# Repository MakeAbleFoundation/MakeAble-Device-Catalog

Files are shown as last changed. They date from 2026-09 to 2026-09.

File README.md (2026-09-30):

# MakeAble assistive devices - print files for the Bambu Lab P1S

Every file here is set up for a **Bambu Lab P1S, 0.4 nozzle, textured PEI plate**, saved in Bambu Studio 2.2.2 format. Open one, check the plate, hit slice. Nothing needs to be re-arranged or re-configured.

## Printer this is for

| | |
|---|---|
| Printer | Bambu Lab **P1S** (256 x 256 x 256 mm build volume) |
| Nozzle | 0.4 mm hardened/stainless (stock) |
| Build plate | Textured PEI |
| Slicer | Bambu Studio 2.2.2 or newer (OrcaSlicer 2.4.2 also opens them) |
| Filaments | PLA (`Bambu PLA Basic @BBL X1C`) and PETG (`PETG P1S Tuned`) - one per plate |

These files are **not** for the A1, A1 mini, X1C, P2S or H2 series without re-checking: the machine settings, bed shape and the P1S's front-left bed exclusion area are baked into every plate. On another printer, re-select the machine preset in Studio and re-check part placement before slicing.

## Repository layout

- `Full Plates/` - one file per device, filled with as many copies as fit.
- `Catalogue - one device per plate.3mf` - devices 01-30, each on its own plate, one copy each, same settings.
- `Catalogue 2 - one device per plate.3mf` - devices 31-48, each on its own plate, one copy each, same settings.
- `Validation/` - what was checked, per file, plus plate previews. `Validation/tools/` holds the Python scripts that built and checked the plates.

## Full plates

| # | file | material | per plate | print time | filament | layer | walls | infill | supports | vs designer's file |
|---|---|---|---|---|---|---|---|---|---|---|
| 01 | 01 Bag Carrier (Medium) - PLA x4.3mf | PLA | 4 copies | 3h 0m 37s | 125.0 g | 0.2 mm | 2 | 15% | no | 100% |
| 02 | 02 Bag Carrier (Small) - PLA x4.3mf | PLA | 4 copies | 2h 41m 50s | 112.0 g | 0.2 mm | 2 | 15% | no | - |
| 03 | 03 Bag Carrier (Large) - PLA x2.3mf | PLA | 2 copies | 1h 49m 24s | 79.0 g | 0.2 mm | 2 | 15% | no | - |
| 04 | 04 Bottle Cap Opener - PETG x8.3mf | PETG | 8 copies | 7h 1m 48s | 166.0 g | 0.2 mm | 5 | 50% | no | 99% |
| 05 | 05 Bottle Opener (three sizes, wide handle) - PETG x4.3mf | PETG | 4 copies | 6h 46m 6s | 141.0 g | 0.2 mm | 5 | 15% | yes | 96% |
| 06 | 06 Assistive Can Tab Opener - PLA x30.3mf | PLA | 30 copies | 11h 8m 48s | 359.0 g | 0.2 mm | 2 | 50% | yes | 99% |
| 07 | 07 OPENSESAME3000 Jar Tool - PETG x2.3mf | PETG | 2 copies | 5h 57m 26s | 147.0 g | 0.12 mm | 3 | 15% | no | 100% |
| 08 | 08 KeyWings - PETG x76.3mf | PETG | 76 copies | 13h 56m 36s | 237.0 g | 0.2 mm | 3 | 20% | no | 95% |
| 09 | 09 DRAG Assistive Writer (kit of 3) - PLA x2.3mf | PLA | 2 kits | 3h 39m 32s | 146.0 g | 0.2 mm | 2 | 15% | no | 100% |
| 10 | 10 Blister Pack Opener - PETG x8.3mf | PETG | 8 copies | 8h 37m 51s | 237.0 g | 0.2 mm | 5 | 17% | yes | - |
| 11 | 11 Pill Popper - PETG x21.3mf | PETG | 21 copies | 8h 22m 50s | 166.0 g | 0.2 mm | 6 | 25% | no | 100% |
| 12 | 12 Clothes Button & Zipper Hook (hook, PETG) - PETG x9.3mf | PETG | 9 copies | 1h 43m 51s | 38.0 g | 0.2 mm | 6 | 25% | no | 96% |
| 13 | 13 Clothes Button & Zipper Hook (handle kit, PLA) - PLA x8.3mf | PLA | 8 kits | 4h 3m 50s | 99.0 g | 0.2 mm | 3/6 | 25% | no | 100% |
| 14 | 14 Flipper Nail Clipper (large clippers) - PLA x3.3mf | PLA | 3 copies | 2h 21m 17s | 91.0 g | 0.2 mm | 2 | 15% | no | 100% |
| 15 | 15 Flipper the Clipper v2 (Thingiverse) - PLA x4.3mf | PLA | 4 copies | 4h 19m 31s | 184.0 g | 0.2 mm | 2 | 80% | no | - |
| 16 | 16 Eating Utensil Aid (kit) - PLA x5.3mf | PLA | 5 kits | 9h 49m 52s | 231.0 g | 0.2 mm | 2 | 60% | no | 100% |
| 17 | 17 Quick-Slip Shoe Horn - PETG x12.3mf | PETG | 12 copies | 11h 46m 18s | 296.0 g | 0.2 mm | 2 | 15% | no | - |
| 18 | 18 Tuber Opener - PLA x12.3mf | PLA | 12 copies | 6h 51m 19s | 203.0 g | 0.16 mm | 4 | 15% | no | 100% |
| 19 | 19 Arthritis Toothbrush Grip - PLA x19.3mf | PLA | 19 copies | 13h 23m 17s | 599.0 g | 0.2 mm | 2 | 15% | no | - |
| 20 | 20 One-Handed Page Holder - PLA x23.3mf | PLA | 23 copies | 8h 10m 32s | 228.0 g | 0.16 mm | 3 | 15% | no | 100% |
| 21 | 21 Smartphone Magnification Stand - PLA x12.3mf | PLA | 12 copies | 10h 10m 51s | 312.0 g | 0.16 mm | 2 | 15% | no | 100% |
| 22 | 22 Eye Drop Assist pliers (bottle 20 mm) - PLA x2.3mf | PLA | 2 copies | 59m 33s | 29.0 g | 0.2 mm | 2 | 15% | no | - |
| 23 | 23 Eye Drop Assist pliers (bottle 22 mm) - PLA x2.3mf | PLA | 2 copies | 59m 19s | 29.0 g | 0.2 mm | 2 | 15% | no | - |
| 24 | 24 Eye Drop Assist pliers (bottle 24 mm) - PLA x2.3mf | PLA | 2 copies | 58m 59s | 29.0 g | 0.2 mm | 2 | 15% | no | - |
| 25 | 25 Eye Drop Assist pliers (bottle 25 mm) - PLA x2.3mf | PLA | 2 copies | 57m 5s | 28.0 g | 0.2 mm | 2 | 15% | no | - |
| 26 | 26 Eye Drop Assist eyepiece 03 A - PLA x35.3mf | PLA | 35 copies | 5h 5m 14s | 118.0 g | 0.2 mm | 2 | 15% | no | - |
| 27 | 27 Eye Drop Assist eyepiece 03 B - PLA x35.3mf | PLA | 35 copies | 4h 42m 50s | 113.0 g | 0.2 mm | 2 | 15% | no | - |
| 28 | 28 Eye Drop Assist eyepiece 03 C - PLA x35.3mf | PLA | 35 copies | 5h 1m 57s | 122.0 g | 0.2 mm | 2 | 15% | no | - |
| 29 | 29 Eye Drop Assist eyepiece 04 D - PLA x35.3mf | PLA | 35 copies | 5h 41m 16s | 137.0 g | 0.2 mm | 2 | 15% | no | - |
| 30 | 30 Eye Drop Assist eyepiece 04 E - PLA x35.3mf | PLA | 35 copies | 5h 21m 16s | 131.0 g | 0.2 mm | 2 | 15% | no | - |
| 31 | 31 Bedside Hook-On Storage Box (kit) - PLA x1.3mf | PLA | 1 kit | 4h 12m 24s | 229.0 g | 0.2 mm | 2 | 15% | no | 100% |
| 32 | 32 Toothpaste Squeezer, external gear (kit) - PLA x8.3mf | PLA | 8 kits | 13h 55m 52s | 323.0 g | 0.2 mm | 3 | 15%/25% | no | 100% |
| 33 | 33 Chopstick Helper (small) - PLA x48.3mf | PLA | 48 copies | 6h 18m 45s | 149.0 g | 0.2 mm | 6 | 100% | no | 99% |
| 34 | 34 Soup Can Opener (no magnets) - PETG x12.3mf | PETG | 12 copies | 6h 12m 36s | 144.0 g | 0.2 mm | 4 | 30% | no | 98% |
| 35 | 35 Jar Opener - Vacuum Releaser - PLA x8.3mf | PLA | 8 copies | 6h 20m 5s | 161.0 g | 0.24 mm | 2 | 10% | no | - |
| 36 | 36 Younger Grip Lid Wrench (no magnets) - PLA x8.3mf | PLA | 8 copies | 9h 20m 1s | 257.0 g | 0.2 mm | 3 | 10% | no | - |
| 37 | 37 Plug Puller (WATAP) - PLA x9.3mf | PLA | 9 copies | 2h 59m 51s | 84.0 g | 0.2 mm | 3 | 25% | no | 98% |
| 38 | 38 Pinky Saver 3 & Phone Stand - PLA x18.3mf | PLA | 18 copies | 5h 8m 33s | 159.0 g | 0.2 mm | 2 | 15% | no | - |
| 39 | 39 Universal Cup Holder (kit) - PLA x1.3mf | PLA | 1 kit | 5h 7m 16s | 202.0 g | 0.2 mm | 6 | 15% | yes | 98% |
| 40 | 40 Adjustable Cane Holder (kit) - PLA x6.3mf | PLA | 6 kits | 12h 45m 2s | 413.0 g | 0.2 mm | 2 | 60% | yes | - |
| 41 | 41 Hand Press - Grip Strengthener (Light) - PETG x5.3mf | PETG | 5 copies | 6h 43m 9s | 194.0 g | 0.2 mm | 4 | 15% | no | 100% |
| 42 | 42 Hand Press - Grip Strengthener (Medium) - PETG x5.3mf | PETG | 5 copies | 7h 33m 56s | 221.0 g | 0.2 mm | 5 | 15% | no | 100% |
| 43 | 43 Hand Press - Grip Strengthener (Hard) - PETG x5.3mf | PETG | 5 copies | 8h 13m 43s | 244.0 g | 0.2 mm | 6 | 15% | no | 100% |
| 44 | 44 Universal Travel Coffee Gimbal (kit) - PETG x2.3mf | PETG | 2 kits | 10h 37m 33s | 287.0 g | 0.2 mm | 4 | 15% | some parts | - |
| 45 | 45 Pen Ball (kit) - PETG x4.3mf | PETG | 4 kits | 11h 36m 55s | 261.0 g | 0.2 mm | 2 | 50% | yes | - |
| 46 | 46 Playing Card Holder (4 rows) - PLA x4.3mf | PLA | 4 copies | 7h 25m 17s | 302.0 g | 0.2 mm | 2 | 15% | no | - |
| 47 | 47 Shoe Lifter - Boot Jack - PLA x2.3mf | PLA | 2 copies | 7h 34m 35s | 282.0 g | 0.2 mm | 2 | 15% | no | 100% |
| 48 | 48 Adaptive Pencil Grip - PLA x7.3mf | PLA | 7 copies | 3h 53m 14s | 143.0 g | 0.2 mm | 2 | 15% | no | - |

All 48 plates together: about 9.0 kg of filament.

The last column is the check that matters: filament per copy on your plate against a slice of the designer's own untouched file. 100% means the part comes out exactly as they set it up. The few at 95-96% are the P1S's elephant-foot compensation shaving the first layer, which their printer profile did not apply. A dash means there is nothing to compare against (loose STLs, or a size variant that shares another file's profile, or a supplied plate, which is its own reference).

## Print-time cap

No plate runs longer than 14 hours (the slicer's estimate). Where a full plate would take longer, it holds fewer copies - the ones in the middle of the plate, kept together:

- **KeyWings**: 76 of the 88 copies that fit (13h 56m 36s)
- **Arthritis Toothbrush Grip**: 19 of the 25 copies that fit (13h 23m 17s)
- **Toothpaste Squeezer, external gear (kit)**: 8 of the 10 kits that fit (13h 55m 52s)
- **Adjustable Cane Holder (kit)**: 6 of the 10 kits that fit (12h 45m 2s)
- **Pen Ball (kit)**: 4 of the 6 kits that fit (11h 36m 55s)

## Catalogue files

A Bambu Studio project holds at most 36 plates, so the one-per-plate catalogue comes in two files.

`Catalogue - one device per plate.3mf` holds 30 plates, one device each, in the same order as the table above. Each plate keeps its own layer height, wall count, infill and support settings - those are baked onto the objects, so switching the process preset in Studio will not silently wipe them.

Filament slot 1 is PLA, slot 2 is PETG, and every plate uses one or the other, so you only ever load one spool per plate.

Three settings cannot vary per plate in Bambu Studio, so the file uses the most conservative value any device asked for:

| setting | catalogue | who wanted something else |
|---|---|---|
| first layer height | 0.2 mm | Bottle Cap Opener's profile uses 0.15 mm |
| first layer speed | 15 mm/s | the slowest any designer asked for (DRAG); others use 20-50 mm/s |
| first layer infill speed | 50 mm/s | slowest of the set |

`Catalogue 2 - one device per plate.3mf` holds 18 plates, one device each, in the same order as the table above. Each plate keeps its own layer height, wall count, infill and support settings - those are baked onto the objects, so switching the process preset in Studio will not silently wipe them.

Three settings cannot vary per plate in Bambu Studio, so the file uses the most conservative value any device asked for:

| setting | catalogue | who wanted something else |
|---|---|---|
| first layer height | 0.2 mm | Jar Opener / Vacuum Releaser's profile uses 0.24 mm |
| first layer speed | 35 mm/s | the slowest any designer asked for (Soup Can Opener); the others use 50 mm/s |
| first layer infill speed | 35 mm/s | slowest of the set |

If you want a device exactly as its designer set it up, use its file in `Full Plates/` - those keep every value.

## Spacing, and the corner the printer cannot use

Parts sit at least 5 mm apart, measured on their real outlines rather than bounding boxes, which is what lets the C-shaped ones nest into each other. Where a profile adds a brim or supports, those reach past the part itself, so the plate is sliced and the spacing widened until the slicer stops reporting conflicting toolpaths:

- **Assistive Can Tab Opener**: 8 mm apart - its tree supports flare out well past the part.
- **Universal Cup Holder (kit)**: 8 mm apart - its tree supports flare out well past the part.
- **Universal Travel Coffee Gimbal (kit)**: 8 mm apart - its tree supports flare out well past the part.

**Blister Pack Opener** is a supplied plate, arranged by hand in Bambu Studio and kept exactly as it is: its parts are 5.75 mm apart, 5.2 mm from the plate edge and 16.6 mm from the excluded corner. It slices with no conflicting toolpaths.

**Younger Grip Lid Wrench (no magnets)** is a supplied plate, arranged by hand in Bambu Studio and kept exactly as it is: its parts are 5 mm apart, 0.7 mm from the plate edge and 20.5 mm from the excluded corner. It slices with no conflicting toolpaths.

**Pinky Saver 3 & Phone Stand** is a supplied plate, arranged by hand in Bambu Studio and kept exactly as it is: its parts are 3.25 mm apart, 3 mm from the plate edge and 3 mm from the excluded corner. It slices with no conflicting toolpaths.

The P1S cannot print in an 18 x 28 mm patch at the front-left corner (Bambu calls it the bed exclusion area). Parts are kept 8 mm clear of it, and any part whose convex hull would still reach into it is dropped - the slicer refuses the whole plate over a single one.

## How the settings were decided

For each device, in order:

1. **Machine settings** always come from the P1S system preset. Nothing from the designer's printer (A1 mini, H2S, X1, X1 Carbon) is carried over - no start/end gcode, no bed shape, no kinematics.
2. **Filament** is your own preset: `PETG P1S Tuned` for PETG, `Bambu PLA Basic @BBL X1C` for PLA.
3. **Speeds, accelerations and elephant-foot compensation** follow the P1S preset, *unless* the designer had deliberately changed that value on their own printer - then their number wins.
4. **Everything else** - walls, infill, shells, supports, brim, seams, line widths, variable layer heights - is the designer's own value from their 3mf.
5. **Loose STLs** have no designer profile: they get the P1S 0.20 mm Standard profile plus only the settings the designer states on the model page.
6. Anything changed on purpose beyond that is listed per file in `Validation/per file/`.
7. **Supplied plates**, arranged by hand in Bambu Studio (Blister Pack Opener, Younger Grip Lid Wrench (no magnets), Pinky Saver 3 & Phone Stand), are delivered exactly as saved, settings included.

## How they were checked

Bambu Studio's command-line slicer crashes on macOS (a known upstream bug), so slicing checks were run with OrcaSlicer 2.4.2, which reads the same project format. Per file:

- the plate slices with no errors, and the time and filament are recorded;
- the plate finishes inside 14 hours;
- filament per copy is compared against a slice of the designer's untouched file, and against the weight quoted on the model page;
- every part is inside the plate, clear of the P1S's excluded front-left corner, with at least 5 mm between parts (checked on the real outlines, not bounding boxes); a supplied plate keeps its own spacing;
- meshes are byte-identical to the designer's, so painted seams survive;
- each object carries its settings, and every object is on a plate; a supplied plate is instead checked byte for byte against the file it came from.

Structural checks: 50 files, 0 problems. All clean.

## Also needed (not printed)

- **Plug Puller (WATAP)**: 2 small zip ties (about 15 cm / 6 in) per puller
- **Pen Ball (kit)**: 5 x #6-32 x 3/4 in round-head screws + 5 x #6-32 hex nuts per ball

## Changed on purpose

- **Jar Opener / Vacuum Releaser**: four mesh vertices forming a 0.36 mm spike under the flat base were moved up onto the base; the part stood on the spike, its first layer was empty and the slicer refused it (the designer's own file fails the same way in OrcaSlicer).

## Worth knowing (nothing was changed)

- **KeyWings**: Body_05*: tall and narrow (21 mm on a 6 mm footprint) with brim off in the designer's profile
- **DRAG Assistive Writer (kit of 3)**: DRAG left plate: 98 mm2 of steep overhang with air under it (max drop 6.1 mm at z=9 mm) while supports are off in the designer's profile - worth a look at the preview
- **DRAG Assistive Writer (kit of 3)**: DRAG right plate: 93 mm2 of steep overhang with air under it (max drop 12.9 mm at z=13 mm) while supports are off in the designer's profile - worth a look at the preview
- **Pill Popper**: Body_08*2: 247 mm2 of steep overhang with air under it (max drop 3.6 mm at z=4 mm) while supports are off in the designer's profile - worth a look at the preview
- **Clothes Button & Zipper Hook (handle kit, PLA)**: Handle+scales.stl: 1157 mm2 of steep overhang with air under it (max drop 5.0 mm at z=5 mm) while supports are off in the designer's profile - worth a look at the preview
- **Flipper Nail Clipper (large clippers)**: Flipper Clipper mod for large size nailcutter.stl: 522 mm2 of steep overhang with air under it (max drop 6.0 mm at z=8 mm) while supports are off in the designer's profile - worth a look at the preview
- **Flipper the Clipper v2 (Thingiverse)**: Flipper the Clipper v2 (Thingiverse): 452 mm2 of steep overhang with air under it (max drop 6.0 mm at z=8 mm) while supports are off in the designer's profile - worth a look at the preview
- **Eating Utensil Aid (kit)**: Spoon Holder.stl: 610 mm2 of steep overhang with air under it (max drop 21.0 mm at z=23 mm) while supports are off in the designer's profile - worth a look at the preview
- **Smartphone Magnification Stand**: Smartphone Magnification Stand.stl: 72 mm2 of steep overhang with air under it (max drop 5.0 mm at z=13 mm) while supports are off in the designer's profile - worth a look at the preview
- **Eye Drop Assist eyepiece 03 A**: Eye Drop Assist eyepiece 03 A: 130 mm2 of steep overhang with air under it (max drop 25.2 mm at z=25 mm) while supports are off in the designer's profile - worth a look at the preview
- **Eye Drop Assist eyepiece 03 C**: Eye Drop Assist eyepiece 03 C: 158 mm2 of steep overhang with air under it (max drop 25.2 mm at z=25 mm) while supports are off in the designer's profile - worth a look at the preview
- **Eye Drop Assist eyepiece 04 D**: Eye Drop Assist eyepiece 04 D: 168 mm2 of steep overhang with air under it (max drop 25.2 mm at z=25 mm) while supports are off in the designer's profile - worth a look at the preview
- **Toothpaste Squeezer, external gear (kit)**: Squeezer base (Seigaiha pattern): 186 mm2 of steep overhang with air under it (max drop 57.0 mm at z=60 mm) while supports are off in the designer's profile - worth a look at the preview
- **Toothpaste Squeezer, external gear (kit)**: Key shaft 0.7 mm (standard): 100 mm2 of steep overhang with air under it (max drop 3.9 mm at z=6 mm) while supports are off in the designer's profile - worth a look at the preview
- **Chopstick Helper (small)**: chopstick_helper_smooth.stl: 115 mm2 of steep overhang with air under it (max drop 6.1 mm at z=8 mm) while supports are off in the designer's profile - worth a look at the preview
- **Soup Can Opener (no magnets)**: Soup Can Opener v5.stl: 235 mm2 of steep overhang with air under it (max drop 3.7 mm at z=5 mm) while supports are off in the designer's profile - worth a look at the preview
- **Jar Opener / Vacuum Releaser**: Body_03: 359 mm2 of steep overhang with air under it (max drop 14.3 mm at z=20 mm) while supports are off in the designer's profile - worth a look at the preview
- **Younger Grip Lid Wrench (no magnets)**: YOUNGER__GRIP_NO Magnets_.stl: 240 mm2 of steep overhang with air under it (max drop 15.4 mm at z=15 mm) while supports are off in the designer's profile - worth a look at the preview
- **Plug Puller (WATAP)**: Plug Puller WATAP.stl: 156 mm2 of steep overhang with air under it (max drop 0.8 mm at z=1 mm) while supports are off in the designer's profile - worth a look at the preview
- **Hand Press / Grip Strengthener (Light)**: Fingergrip Press Light.stl: 67 mm2 of steep overhang with air under it (max drop 4.0 mm at z=10 mm) while supports are off in the designer's profile - worth a look at the preview
- **Hand Press / Grip Strengthener (Medium)**: Fingergrip Press Medium.stl: 67 mm2 of steep overhang with air under it (max drop 4.0 mm at z=10 mm) while supports are off in the designer's profile - worth a look at the preview
- **Hand Press / Grip Strengthener (Hard)**: Fingergrip Press Hard.stl: 67 mm2 of steep overhang with air under it (max drop 4.0 mm at z=10 mm) while supports are off in the designer's profile - worth a look at the preview
- **Universal Travel Coffee Gimbal (kit)**: Gimbal: 327 mm2 of steep overhang with air under it (max drop 2.0 mm at z=14 mm) while supports are off in the designer's profile - worth a look at the preview
- **Universal Travel Coffee Gimbal (kit)**: Bolt: 86 mm2 of steep overhang with air under it (max drop 3.7 mm at z=4 mm) while supports are off in the designer's profile - worth a look at the preview
- **Shoe Lifter / Boot Jack**: SchuhauszieherV2.stl_A_A: 11300 mm2 of steep overhang with air under it (max drop 92.0 mm at z=92 mm) while supports are off in the designer's profile - worth a look at the preview

## Where each file came from

| # | device | designer source file (kept locally, not in this repo) | model page |
|---|---|---|---|
| 01 | Bag Carrier (Medium) | `Bag Carrier (PLA)/Bag+Carrier+Medium.3mf` | [page](https://makerworld.com/en/models/1715311-bag-carrier#profileId-1820526) |
| 02 | Bag Carrier (Small) | `Bag Carrier (PLA)/Bag+Carrier+Medium.3mf` | [page](https://makerworld.com/en/models/1715311-bag-carrier) |
| 03 | Bag Carrier (Large) | `Bag Carrier (PLA)/Bag+Carrier+Medium.3mf` | [page](https://makerworld.com/en/models/1715311-bag-carrier) |
| 04 | Bottle Cap Opener | `Bottle Opener (PETG)/Bottle+Cap+Opener.3mf` | [page](https://makerworld.com/en/models/1093642-bottle-cap-opener#profileId-1087614) |
| 05 | Bottle Opener (three sizes, wide handle) | `Bottle Opener (PETG)/Bottle+Opener+remix+without+support+material.3mf` | [page](https://makerworld.com/en/models/712423-bottle-opener-three-sizes-wider-handle#profileId-642822) |
| 06 | Assistive Can Tab Opener | `Can Opener (PLA)/Base_Can_Opener.3mf` | [page](https://makerworld.com/en/models/1797256-assistive-can-tab-opener#profileId-1916191) |
| 07 | OPENSESAME3000 Jar Tool | `Jar Opener (PETG)/opensesame.3mf` | [page](https://makerworld.com/en/models/90424-opensesame3000-jar-tool#profileId-96804) |
| 08 | KeyWings | `Key Holder (PETG)/KeyWings+v6+Bambu.3mf` | [page](https://makerworld.com/en/models/1688156-keywings-for-mobility-needs#profileId-1789186) |
| 09 | DRAG Assistive Writer (kit of 3) | `DRAG Assistive Writer (PLA)/DRAG+v2 (1).3mf` | [page](https://makerworld.com/en/models/869468-drag-assistive-writing-and-drawing-device#profileId-821115) |
| 10 | Blister Pack Opener | `New Devices/BlisterPackOpener_x8.3mf` | [page](https://makerworld.com/en/models/1791626-blister-pack-opener#profileId-1909450) |
| 11 | Pill Popper | `Pill Popper (PETG)/Pill+Popper+Bambu+Studio.3mf` | [page](https://makerworld.com/en/models/1440419-pill-popper#profileId-1499190) |
| 12 | Clothes Button & Zipper Hook (hook, PETG) | `Clothes Button and Zipper Aid (PETG + PLA)/central-loop-and-hook-button-and-zipper-hook.3mf` | [page](https://makerworld.com/en/models/423231-clothes-button-and-zipper-hook-helper) |
| 13 | Clothes Button & Zipper Hook (handle kit, PLA) | `Clothes Button and Zipper Aid (PETG + PLA)/central-loop-and-hook-button-and-zipper-hook.3mf` | [page](https://makerworld.com/en/models/423231-clothes-button-and-zipper-hook-helper) |
| 14 | Flipper Nail Clipper (large clippers) | `Nail Clipper Holder (PLA)/Flipper+Clipper+mod+for+large+size+nailcutter_a1mini.3mf` | [page](https://makerworld.com/en/models/47915-flipper-the-one-handed-nail-clipper-adjusted-for-l) |
| 15 | Flipper the Clipper v2 (Thingiverse) | `Nail Clipper Holder (PLA)/Nailcutter_v2.stl` | [page](https://www.thingiverse.com/thing:5637570) |
| 16 | Eating Utensil Aid (kit) | `Eating Utensil Aid (PLA)/Eating+Utensil+Aid.3mf` | [page](https://makerworld.com/en/models/192317-eating-utensil-aid-no-supports-updated-v2-files-in#profileId-212499) |
| 17 | Quick-Slip Shoe Horn | `Shoe Horn (PETG)/Shoe+Horn+3MF.3mf` | [page](https://makerworld.com/en/models/1024414-quick-slip-shoe-horn#profileId-1006338) |
| 18 | Tuber Opener | `Tube Opener/Tube_Opener.3mf` | [page](https://makerworld.com/en/models/1737344-tuber-opener#profileId-1845987) |
| 19 | Arthritis Toothbrush Grip | `Toothbrush Grip (PLA)/6066726cbda58_arthritis-toothbrush-grip/toofbrushgrip.stl` | [page](https://www.myminifactory.com/object/3d-print-arthritis-toothbrush-grip-77601) |
| 20 | One-Handed Page Holder | `Other/One_Handed_Book_Holder.3mf` | [page](https://makerworld.com/en/models/1740474-one-handed-page-holder#profileId-1849552) |
| 21 | Smartphone Magnification Stand | `Other/Smartphone+Magnification+Stand.3mf` | [page](https://makerworld.com/en/models/1737380-smartphone-magnification-stand#profileId-1846025) |
| 22 | Eye Drop Assist pliers (bottle 20 mm) | `Eye Drop Assist (PLA)/edab_pliers_07_bd20.stl` | [page](https://www.printables.com/model/1031668-eye-drop-assist-for-bottles) |
| 23 | Eye Drop Assist pliers (bottle 22 mm) | `Eye Drop Assist (PLA)/edab_pliers_07_bd22.stl` | [page](https://www.printables.com/model/1031668-eye-drop-assist-for-bottles) |
| 24 | Eye Drop Assist pliers (bottle 24 mm) | `Eye Drop Assist (PLA)/edab_pliers_07_bd24.stl` | [page](https://www.printables.com/model/1031668-eye-drop-assist-for-bottles) |
| 25 | Eye Drop Assist pliers (bottle 25 mm) | `Eye Drop Assist (PLA)/EDA_Pliers_Bottle_06Bc_BD25.stl` | [page](https://www.printables.com/model/1031668-eye-drop-assist-for-bottles) |
| 26 | Eye Drop Assist eyepiece 03 A | `Eye Drop Assist (PLA)/EDA_EyePiece_03_A.stl` | [page](https://www.printables.com/model/1031668-eye-drop-assist-for-bottles) |
| 27 | Eye Drop Assist eyepiece 03 B | `Eye Drop Assist (PLA)/EDA_EyePiece_03_B.stl` | [page](https://www.printables.com/model/1031668-eye-drop-assist-for-bottles) |
| 28 | Eye Drop Assist eyepiece 03 C | `Eye Drop Assist (PLA)/EDA_EyePiece_03_C.stl` | [page](https://www.printables.com/model/1031668-eye-drop-assist-for-bottles) |
| 29 | Eye Drop Assist eyepiece 04 D | `Eye Drop Assist (PLA)/eda_eyepiece_04_d.stl` | [page](https://www.printables.com/model/1031668-eye-drop-assist-for-bottles) |
| 30 | Eye Drop Assist eyepiece 04 E | `Eye Drop Assist (PLA)/eda_eyepiece_04_e.stl` | [page](https://www.printables.com/model/1031668-eye-drop-assist-for-bottles) |
| 31 | Bedside Hook-On Storage Box (kit) | `New Devices/Bedside+Holder+v3.3mf` | [page](https://makerworld.com/en/models/1051323-bedside-hook-on-storage-box-organizer#profileId-1038131) |
| 32 | Toothpaste Squeezer, external gear (kit) | `New Devices/ToothSqeez_ExterGear_SeigaihaPattern.3mf` | [page](https://makerworld.com/en/models/2423006-toothpaste-squeezer-external-gear#profileId-2657457) |
| 33 | Chopstick Helper (small) | `New Devices/chopstick_helper_new_design_PLA_Small.3mf` | [page](https://makerworld.com/en/models/1088273-chopstick-helper-refreshed-design#profileId-1082781) |
| 34 | Soup Can Opener (no magnets) | `New Devices/Soup+Can+Opener+-+no+pause+for+magnets.3mf` | [page](https://makerworld.com/en/models/1030162-soup-can-opener-for-poor-grip-strength#profileId-1012846) |
| 35 | Jar Opener / Vacuum Releaser | `New Devices/Jar+Opener+Bambu+ULTRA+FAST.3mf` | [page](https://makerworld.com/en/models/1642031-jar-opener-tuned-for-all-bambu-printers#profileId-1735123) |
| 36 | Younger Grip Lid Wrench (no magnets) | `New Devices/PRJ___YOUNGER_GRIP_NO_Magnets_.3mf` | [page](https://makerworld.com/en/models/1493731-younger-grip-lid-wrench-arthritis-aid#profileId-1572614) |
| 37 | Plug Puller (WATAP) | `New Devices/Plug+Puller+by+WATAP.3mf` | [page](https://makerworld.com/en/models/421822-plug-puller-assistive-technology-by-watap#profileId-324742) |
| 38 | Pinky Saver 3 & Phone Stand | `New Devices/PinkySaver3_x19.3mf` | [page](https://makerworld.com/en/models/1842862-pinky-saver-3#profileId-1969044) |
| 39 | Universal Cup Holder (kit) | `New Devices/STOLLER_CUP_HOLDER_v2.0.3mf` | [page](https://makerworld.com/en/models/1969980-universal-cup-holder#profileId-2118034) |
| 40 | Adjustable Cane Holder (kit) | `New Devices/adjustable-cane-holder-model_files/Recommended Print Files/texture_on_cane_holder_v3.stl (+2 more)` | [page](https://www.printables.com/model/203631-adjustable-cane-holder) |
| 41 | Hand Press / Grip Strengthener (Light) | `New Devices/Fingergrip+Press (1).3mf` | [page](https://makerworld.com/en/models/531052-hand-press-grip-strengthening#profileId-447870) |
| 42 | Hand Press / Grip Strengthener (Medium) | `New Devices/Fingergrip+Press (1).3mf` | [page](https://makerworld.com/en/models/531052-hand-press-grip-strengthening#profileId-447870) |
| 43 | Hand Press / Grip Strengthener (Hard) | `New Devices/Fingergrip+Press (1).3mf` | [page](https://makerworld.com/en/models/531052-hand-press-grip-strengthening#profileId-447870) |
| 44 | Universal Travel Coffee Gimbal (kit) | `New Devices/universal-travel-coffee-gimbal-model_files/Gimbal.stl (+3 more)` | [page](https://www.printables.com/model/129329-universal-travel-coffee-gimbal) |
| 45 | Pen Ball (kit) | `New Devices/Pen Ball - 2810069/files/Pen_Ball_Top_v.1.0.0.STL (+1 more)` | [page](https://www.thingiverse.com/thing:2810069) |
| 46 | Playing Card Holder (4 rows) | `New Devices/Full Size Playing Card Holder - 2863434/files/holder-4row.stl` | [page](https://www.thingiverse.com/thing:2863434) |
| 47 | Shoe Lifter / Boot Jack | `New Devices/SchuhauszieherV2 (1).3mf` | [page](https://makerworld.com/en/models/1040127-shoe-lifter-boot-jack#profileId-1024783) |
| 48 | Adaptive Pencil Grip | `New Devices/adaptive-pencil-grip-model_files/Adaptive writer.stl` | [page](https://www.printables.com/model/520212-adaptive-pencil-grip) |

Each MakerWorld link's profile id was matched against the `DesignProfileId` stored inside the local 3mf, so these are the exact profiles that were linked. The links for 19-21 (Arthritis Toothbrush Grip, One-Handed Page Holder, Smartphone Magnification Stand) were added afterwards from the model pages themselves.

## Look-alikes that were left out

- `Other/EyeDropperAid.3mf` - MakeAble 'Eye Dropper Squeezer Aid' - a different model from the Printables Eye Drop Assist on the list
- `Other/jar-opener+(1).3mf` - MakeAble 'Jar/Pop Bottle and Can Assist' - not the OPENSESAME3000 jar tool
- `Other/4+in+1+button+aid,+key+turner,+zipper+aid,+handle.3mf` - MakeAble 4-in-1 aid - not the Clothes Button & Zipper Hook helper
- `Other/Bottle_Opener_30.stl + .gcode` - a third bottle opener, sliced for a Prusa MK3S
- `Toothbrush Grip (PLA)/toothbrush.STL` - the flat MyMiniFactory toothbrush, not the round arthritis grip you picked
- `Walking Stick Holder/` - not on the catalogue list
- `Other/DRAG+v2.3mf` - byte-identical copy of the DRAG folder's 3mf
- `Other/Tube_Opener.3mf` - plain mesh export with no settings in it
- `Aug*.3mf, Combined*.3mf, Bag_Carrier_x4.3mf` - earlier working files, not designer sources
- `Clothes Button .../*.stl (loose)` - the loose STLs differ from the 3mf: its pins are scaled to 95% and its hook carries painted seams

From the second batch (`New Devices/`):

- `adjustable-cane-holder-model_files/Design History Files/, Alternative Files/` - the designer's earlier versions and work-in-progress latch; their 'Recommended Print Files' are used
- `universal-travel-coffee-gimbal-model_files/Optional *.stl` - optional extras (long bolt, nut, cup and flat-surface adapters, vertical gimbal, TPU bar wrap); the kit is gimbal + clamp + bolt + washer
- `universal-travel-coffee-gimbal-model_files/MPC Washer.3mf, *.step, *.f3d` - a plain mesh of the washer STL that is used, and the CAD sources
- `Full Size Playing Card Holder - 2863434/files/holder.stl, case-*.stl` - the original 3-row holder and the storage cases; the 4-row holder is the one on the list
- `Full Size Playing Card Holder - 2863434/files/holder-4rows.stl` - same shape as holder-4row.stl
- `adaptive-pencil-grip-model_files/Test print.stl` - a small pencil-fit test piece
- `PRJ___YOUNGER+GRIP_Glue-in+Magnets_.3mf` - the earlier glue-in-magnets profile, replaced by the no-magnets plate
- `ToothSqeez_ExterGear_SeigaihaPattern.3mf, plates 4-6` - the 1.0, 1.3 and 1.6 mm key shafts for thicker tube ends; the kit uses the 0.7 mm standard shaft
- `Fingergrip+Press (1).3mf` - one file, three devices: each strength gets its own plate

## Still open

- **Eye Drop Assist (files 22-30)**: the three Printables pages sit behind a bot check, so the designer's own print settings could not be read. Those files use the P1S 0.20 mm Standard profile in PLA. They also need a decision: whether a pliers and an eyepiece pair up into one device (in which case they should be kit plates) or are alternatives.
- **Universal Cup Holder**: the designer's painted brim ears are carried over, but OrcaSlicer (used for these checks) does not read painted ears. Worth a glance at the first layer in Bambu Studio's preview before the first print.

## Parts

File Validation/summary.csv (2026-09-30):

id | file | device | material | per_plate | objects | print_time | grams | cm3 | cm3_per_unit | reference_cm3_per_unit | match | page_grams | layer | walls | infill | supports | brim | preset | slice_ok | geometry_issues | advisories
1 | 01 Bag Carrier (Medium) - PLA x4.3mf | Bag Carrier (Medium) | PLA | 4 copies | 4 | 3h 0m 37s | 125.4 | 99.5 | 24.88 | 24.93 | 100% | 32 | 0.2 | 2 | 15% | 0 | auto_brim | 0.20mm Standard @BBL X1C | True | 0 | 0
2 | 02 Bag Carrier (Small) - PLA x4.3mf | Bag Carrier (Small) | PLA | 4 copies | 4 | 2h 41m 50s | 112.5 | 89.2 | 22.31 |  | - |  | 0.2 | 2 | 15% | 0 | auto_brim | 0.20mm Standard @BBL X1C | True | 0 | 0
3 | 03 Bag Carrier (Large) - PLA x2.3mf | Bag Carrier (Large) | PLA | 2 copies | 2 | 1h 49m 24s | 78.9 | 62.6 | 31.32 |  | - |  | 0.2 | 2 | 15% | 0 | auto_brim | 0.20mm Standard @BBL X1C | True | 0 | 0
4 | 04 Bottle Cap Opener - PETG x8.3mf | Bottle Cap Opener | PETG | 8 copies | 8 | 7h 1m 48s | 166.0 | 132.8 | 16.6 | 16.68 | 99% | 22 | 0.2 | 5 | 50% | 0 | auto_brim | 0.20mm Standard @BBL X1C | True | 0 | 0
5 | 05 Bottle Opener (three sizes, wide handle) - PETG x4.3mf | Bottle Opener (three sizes, wide handle) | PETG | 4 copies | 4 | 6h 46m 6s | 141.1 | 112.9 | 28.22 | 29.4 | 96% | 35 | 0.2 | 5 | 15% | 1 | auto_brim | 0.20mm Strength @BBL X1C | True | 0 | 0
6 | 06 Assistive Can Tab Opener - PLA x30.3mf | Assistive Can Tab Opener | PLA | 30 copies | 30 | 11h 8m 48s | 358.8 | 284.7 | 9.49 | 9.57 | 99% | 12 | 0.2 | 2 | 50% | 1 | auto_brim | 0.20mm Standard @BBL X1C | True | 0 | 0
7 | 07 OPENSESAME3000 Jar Tool - PETG x2.3mf | OPENSESAME3000 Jar Tool | PETG | 2 copies | 2 | 5h 57m 26s | 147.1 | 117.7 | 58.83 | 58.94 | 100% | 74 | 0.12 | 3 | 15% | 0 | auto_brim | 0.12mm Fine @BBL X1C | True | 0 | 0
8 | 08 KeyWings - PETG x76.3mf | KeyWings | PETG | 76 copies | 76 | 13h 56m 36s | 237.0 | 189.6 | 2.49 | 2.63 | 95% | 4 | 0.2 | 3 | 20% | 0 | no_brim | 0.20mm Standard @BBL X1C | True | 0 | 1
9 | 09 DRAG Assistive Writer (kit of 3) - PLA x2.3mf | DRAG Assistive Writer (kit of 3) | PLA | 2 kits | 6 | 3h 39m 32s | 146.4 | 116.2 | 58.11 | 58.06 | 100% | 76 | 0.2 | 2 | 15% | 0 | no_brim | 0.20mm Standard @BBL X1C | True | 0 | 2
10 | 10 Blister Pack Opener - PETG x8.3mf | Blister Pack Opener | PETG | 8 copies | 8 | 8h 37m 51s | 237.2 | 189.7 | 23.72 |  | - | 33 | 0.2 | 5 | 17% | 1 | outer_only | 0.20mm Standard @BBL X1C | True | 0 | 0
11 | 11 Pill Popper - PETG x21.3mf | Pill Popper | PETG | 21 copies | 21 | 8h 22m 50s | 165.8 | 132.6 | 6.32 | 6.29 | 100% | 9 | 0.2 | 6 | 25% | 0 | auto_brim | 0.20mm Strength @BBL X1C | True | 0 | 1
12 | 12 Clothes Button & Zipper Hook (hook, PETG) - PETG x9.3mf | Clothes Button & Zipper Hook (hook, PETG) | PETG | 9 copies | 9 | 1h 43m 51s | 37.9 | 30.3 | 3.37 | 3.5 | 96% |  | 0.2 | 6 | 25% | 0 | auto_brim | 0.20mm Strength @BBL X1C | True | 0 | 0
13 | 13 Clothes Button & Zipper Hook (handle kit, PLA) - PLA x8.3mf | Clothes Button & Zipper Hook (handle kit, PLA) | PLA | 8 kits | 32 | 4h 3m 50s | 98.6 | 78.3 | 9.79 | 9.81 | 100% |  | 0.2 | 3/6 | 25% | 0 | auto_brim | 0.20mm Strength @BBL X1C | True | 0 | 1
14 | 14 Flipper Nail Clipper (large clippers) - PLA x3.3mf | Flipper Nail Clipper (large clippers) | PLA | 3 copies | 3 | 2h 21m 17s | 90.8 | 72.1 | 24.02 | 23.96 | 100% | 30 | 0.2 | 2 | 15% | 0 | auto_brim | 0.20mm Standard @BBL X1C | True | 0 | 1
15 | 15 Flipper the Clipper v2 (Thingiverse) - PLA x4.3mf | Flipper the Clipper v2 (Thingiverse) | PLA | 4 copies | 4 | 4h 19m 31s | 184.0 | 146.0 | 36.5 |  | - |  | 0.2 | 2 | 80% | 0 | auto_brim | 0.20mm Standard @BBL X1C | True | 0 | 1
16 | 16 Eating Utensil Aid (kit) - PLA x5.3mf | Eating Utensil Aid (kit) | PLA | 5 kits | 10 | 9h 49m 52s | 231.2 | 183.5 | 36.7 | 36.8 | 100% | 45 | 0.2 | 2 | 60% | 0 | auto_brim | 0.20mm Standard @BBL X1C | True | 0 | 1
17 | 17 Quick-Slip Shoe Horn - PETG x12.3mf | Quick-Slip Shoe Horn | PETG | 12 copies | 12 | 11h 46m 18s | 296.5 | 237.2 | 19.76 |  | - | 25 | 0.2 | 2 | 15% | 0 | auto_brim | 0.20mm Standard @BBL X1C | True | 0 | 0
18 | 18 Tuber Opener - PLA x12.3mf | Tuber Opener | PLA | 12 copies | 12 | 6h 51m 19s | 202.7 | 160.9 | 13.41 | 13.43 | 100% | 17 | 0.16 | 4 | 15% | 0 | auto_brim | 0.16mm Optimal @BBL X1C | True | 0 | 0
19 | 19 Arthritis Toothbrush Grip - PLA x19.3mf | Arthritis Toothbrush Grip | PLA | 19 copies | 19 | 13h 23m 17s | 599.3 | 475.6 | 25.03 |  | - |  | 0.2 | 2 | 15% | 0 | auto_brim | 0.20mm Standard @BBL X1C | True | 0 | 0
20 | 20 One-Handed Page Holder - PLA x23.3mf | One-Handed Page Holder | PLA | 23 copies | 23 | 8h 10m 32s | 228.1 | 181.0 | 7.87 | 7.87 | 100% |  | 0.16 | 3 | 15% | 0 | auto_brim | 0.16mm Optimal @BBL X1C | True | 0 | 0
21 | 21 Smartphone Magnification Stand - PLA x12.3mf | Smartphone Magnification Stand | PLA | 12 copies | 12 | 10h 10m 51s | 312.1 | 247.7 | 20.64 | 20.73 | 100% |  | 0.16 | 2 | 15% | 0 | auto_brim | 0.16mm Optimal @BBL X1C | True | 0 | 1
22 | 22 Eye Drop Assist pliers (bottle 20 mm) - PLA x2.3mf | Eye Drop Assist pliers (bottle 20 mm) | PLA | 2 copies | 2 | 59m 33s | 29.0 | 23.0 | 11.5 |  | - |  | 0.2 | 2 | 15% | 0 | auto_brim | 0.20mm Standard @BBL X1C | True | 0 | 0
23 | 23 Eye Drop Assist pliers (bottle 22 mm) - PLA x2.3mf | Eye Drop Assist pliers (bottle 22 mm) | PLA | 2 copies | 2 | 59m 19s | 28.7 | 22.8 | 11.4 |  | - |  | 0.2 | 2 | 15% | 0 | auto_brim | 0.20mm Standard @BBL X1C | True | 0 | 0
24 | 24 Eye Drop Assist pliers (bottle 24 mm) - PLA x2.3mf | Eye Drop Assist pliers (bottle 24 mm) | PLA | 2 copies | 2 | 58m 59s | 28.6 | 22.7 | 11.34 |  | - |  | 0.2 | 2 | 15% | 0 | auto_brim | 0.20mm Standard @BBL X1C | True | 0 | 0
25 | 25 Eye Drop Assist pliers (bottle 25 mm) - PLA x2.3mf | Eye Drop Assist pliers (bottle 25 mm) | PLA | 2 copies | 2 | 57m 5s | 27.9 | 22.2 | 11.08 |  | - |  | 0.2 | 2 | 15% | 0 | auto_brim | 0.20mm Standard @BBL X1C | True | 0 | 0
26 | 26 Eye Drop Assist eyepiece 03 A - PLA x35.3mf | Eye Drop Assist eyepiece 03 A | PLA | 35 copies | 35 | 5h 5m 14s | 117.7 | 93.4 | 2.67 |  | - |  | 0.2 | 2 | 15% | 0 | auto_brim | 0.20mm Standard @BBL X1C | True | 0 | 1
27 | 27 Eye Drop Assist eyepiece 03 B - PLA x35.3mf | Eye Drop Assist eyepiece 03 B | PLA | 35 copies | 35 | 4h 42m 50s | 113.4 | 90.0 | 2.57 |  | - |  | 0.2 | 2 | 15% | 0 | auto_brim | 0.20mm Standard @BBL X1C | True | 0 | 0
28 | 28 Eye Drop Assist eyepiece 03 C - PLA x35.3mf | Eye Drop Assist eyepiece 03 C | PLA | 35 copies | 35 | 5h 1m 57s | 122.5 | 97.2 | 2.78 |  | - |  | 0.2 | 2 | 15% | 0 | auto_brim | 0.20mm Standard @BBL X1C | True | 0 | 1
29 | 29 Eye Drop Assist eyepiece 04 D - PLA x35.3mf | Eye Drop Assist eyepiece 04 D | PLA | 35 copies | 35 | 5h 41m 16s | 136.7 | 108.5 | 3.1 |  | - |  | 0.2 | 2 | 15% | 0 | auto_brim | 0.20mm Standard @BBL X1C | True | 0 | 1
30 | 30 Eye Drop Assist eyepiece 04 E - PLA x35.3mf | Eye Drop Assist eyepiece 04 E | PLA | 35 copies | 35 | 5h 21m 16s | 130.9 | 103.9 | 2.97 |  | - |  | 0.2 | 2 | 15% | 0 | auto_brim | 0.20mm Standard @BBL X1C | True | 0 | 0
31 | 31 Bedside Hook-On Storage Box (kit) - PLA x1.3mf | Bedside Hook-On Storage Box (kit) | PLA | 1 kit | 3 | 4h 12m 24s | 229.0 | 181.7 | 181.72 | 181.24 | 100% | 223 | 0.2 | 2 | 15% | 0 | auto_brim | 0.20mm Standard @BBL X1C | True | 0 | 0
32 | 32 Toothpaste Squeezer, external gear (kit) - PLA x8.3mf | Toothpaste Squeezer, external gear (kit) | PLA | 8 kits | 24 | 13h 55m 52s | 323.4 | 256.6 | 32.08 | 32.17 | 100% | 42 | 0.2 | 3 | 15%/25% | 0 | auto_brim | 0.20mm Standard @BBL X1C | True | 0 | 2
33 | 33 Chopstick Helper (small) - PLA x48.3mf | Chopstick Helper (small) | PLA | 48 copies | 48 | 6h 18m 45s | 149.2 | 118.4 | 2.47 | 2.48 | 99% | 4 | 0.2 | 6 | 100% | 0 | auto_brim | 0.20mm Standard @BBL X1C | True | 0 | 1
34 | 34 Soup Can Opener (no magnets) - PETG x12.3mf | Soup Can Opener (no magnets) | PETG | 12 copies | 12 | 6h 12m 36s | 143.7 | 115.0 | 9.58 | 9.82 | 98% | 13 | 0.2 | 4 | 30% | 0 | auto_brim | 0.20mm Strength @BBL X1C | True | 0 | 1
35 | 35 Jar Opener - Vacuum Releaser - PLA x8.3mf | Jar Opener / Vacuum Releaser | PLA | 8 copies | 8 | 6h 20m 5s | 161.4 | 128.1 | 16.01 |  | - | 22 | 0.24 | 2 | 10% | 0 | no_brim | 0.24mm Draft @BBL X1C | True | 0 | 1
36 | 36 Younger Grip Lid Wrench (no magnets) - PLA x8.3mf | Younger Grip Lid Wrench (no magnets) | PLA | 8 copies | 8 | 9h 20m 1s | 257.3 | 204.2 | 25.52 |  | - | 33 | 0.2 | 3 | 10% | 0 | auto_brim | 0.20mm Standard @BBL X1C | True | 0 | 1
37 | 37 Plug Puller (WATAP) - PLA x9.3mf | Plug Puller (WATAP) | PLA | 9 copies | 9 | 2h 59m 51s | 84.2 | 66.8 | 7.42 | 7.59 | 98% | 10 | 0.2 | 3 | 25% | 0 | auto_brim | 0.20mm Strength @BBL X1C | True | 0 | 1
38 | 38 Pinky Saver 3 & Phone Stand - PLA x18.3mf | Pinky Saver 3 & Phone Stand | PLA | 18 copies | 18 | 5h 8m 33s | 159.0 | 126.2 | 7.01 |  | - | 9 | 0.2 | 2 | 15% | 0 | auto_brim | 0.20mm Standard @BBL X1C | True | 0 | 0
39 | 39 Universal Cup Holder (kit) - PLA x1.3mf | Universal Cup Holder (kit) | PLA | 1 kit | 10 | 5h 7m 16s | 201.8 | 160.2 | 160.19 | 162.7 | 98% | 200 | 0.2 | 6 | 15% | 1 | brim_ears | 0.20mm Standard @BBL X1C | True | 0 | 0
40 | 40 Adjustable Cane Holder (kit) - PLA x6.3mf | Adjustable Cane Holder (kit) | PLA | 6 kits | 18 | 12h 45m 2s | 413.3 | 328.0 | 54.66 |  | - |  | 0.2 | 2 | 60% | 1 | auto_brim/outer_only | 0.20mm Standard @BBL X1C | True | 0 | 0
41 | 41 Hand Press - Grip Strengthener (Light) - PETG x5.3mf | Hand Press / Grip Strengthener (Light) | PETG | 5 copies | 5 | 6h 43m 9s | 194.3 | 155.4 | 31.09 | 31.19 | 100% | 39 | 0.2 | 4 | 15% | 0 | auto_brim | 0.20mm Standard @BBL X1C | True | 0 | 1
42 | 42 Hand Press - Grip Strengthener (Medium) - PETG x5.3mf | Hand Press / Grip Strengthener (Medium) | PETG | 5 copies | 5 | 7h 33m 56s | 221.1 | 176.9 | 35.38 | 35.48 | 100% | 45 | 0.2 | 5 | 15% | 0 | auto_brim | 0.20mm Standard @BBL X1C | True | 0 | 1
43 | 43 Hand Press - Grip Strengthener (Hard) - PETG x5.3mf | Hand Press / Grip Strengthener (Hard) | PETG | 5 copies | 5 | 8h 13m 43s | 243.9 | 195.2 | 39.03 | 39.21 | 100% | 49 | 0.2 | 6 | 15% | 0 | auto_brim | 0.20mm Standard @BBL X1C | True | 0 | 1
44 | 44 Universal Travel Coffee Gimbal (kit) - PETG x2.3mf | Universal Travel Coffee Gimbal (kit) | PETG | 2 kits | 8 | 10h 37m 33s | 287.1 | 229.7 | 114.84 |  | - |  | 0.2 | 4 | 15% | some | auto_brim | 0.20mm Standard @BBL X1C | True | 0 | 2
45 | 45 Pen Ball (kit) - PETG x4.3mf | Pen Ball (kit) | PETG | 4 kits | 8 | 11h 36m 55s | 261.4 | 209.1 | 52.28 |  | - |  | 0.2 | 2 | 50% | 1 | auto_brim | 0.20mm Standard @BBL X1C | True | 0 | 0
46 | 46 Playing Card Holder (4 rows) - PLA x4.3mf | Playing Card Holder (4 rows) | PLA | 4 copies | 4 | 7h 25m 17s | 302.5 | 240.1 | 60.02 |  | - |  | 0.2 | 2 | 15% | 0 | auto_brim | 0.20mm Standard @BBL X1C | True | 0 | 0
47 | 47 Shoe Lifter - Boot Jack - PLA x2.3mf | Shoe Lifter / Boot Jack | PLA | 2 copies | 2 | 7h 34m 35s | 282.3 | 224.1 | 112.03 | 111.71 | 100% | 141 | 0.2 | 2 | 15% | 0 | auto_brim | 0.20mm Standard @BBL X1C | True | 0 | 1
48 | 48 Adaptive Pencil Grip - PLA x7.3mf | Adaptive Pencil Grip | PLA | 7 copies | 7 | 3h 53m 14s | 143.0 | 113.5 | 16.21 |  | - |  | 0.2 | 2 | 15% | 0 | auto_brim | 0.20mm Standard @BBL X1C | True | 0 | 0

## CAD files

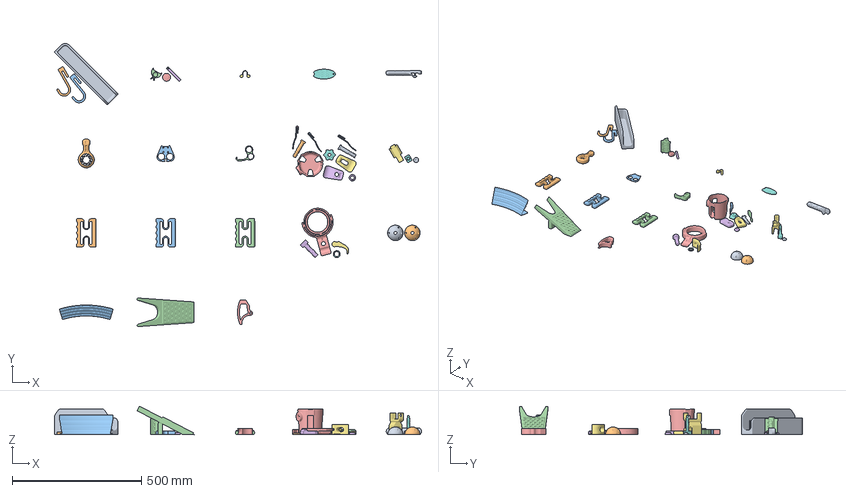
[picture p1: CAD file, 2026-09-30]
Catalogue 2 - one device per plate.3mf
1420.0 x 1094.5 x 110.2 mm
Bedside Holder v3.stl
Bedside Holder v3 hook.stl x 2
Squeezer base (Seigaiha pattern)
Key head
Key shaft 0.7 mm (standard)
chopstick_helper_smooth.stl
Soup Can Opener v5.stl
YOUNGER__GRIP_NO Magnets_.stl
Plug Puller WATAP.stl
pinky saver 3.stl
UPDATED CUP.stp
JOY-000280234
JOY-000280230
KNOB.stp
SCREW.stp_B
SCREW.stp_A
FINGERS.stp x 3
SPACER.stp
Cane holder (textured clamp)
Clamp screw (easy grip)
Clamp protector
Fingergrip Press Light.stl
Fingergrip Press Medium.stl
Fingergrip Press Hard.stl
Gimbal
Bolt
Clamp
Washer
Pen Ball top
Pen Ball bottom
Playing Card Holder (4 rows)
SchuhauszieherV2.stl_A_A
Adaptive Pencil Grip

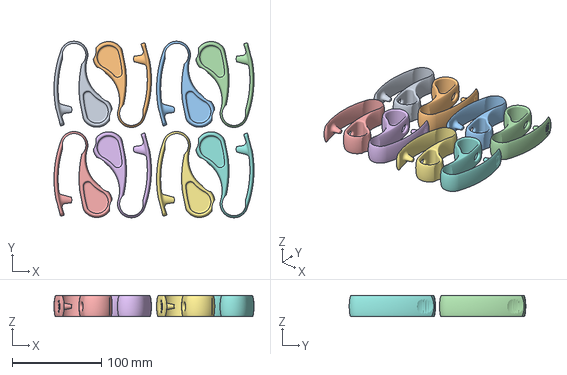
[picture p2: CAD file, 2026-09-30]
Full Plates/10 Blister Pack Opener - PETG x8.3mf
224.3 x 198.0 x 24.0 mm
Blister Pack Opener.step x 8

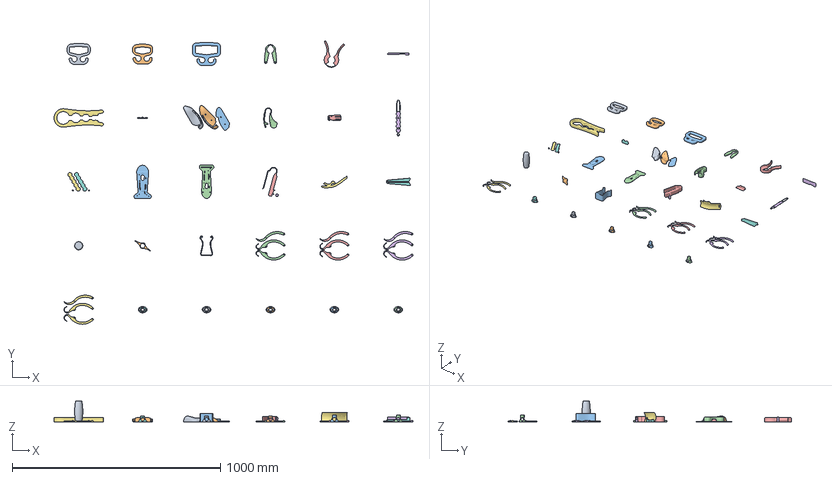
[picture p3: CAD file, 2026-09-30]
Catalogue - one device per plate.3mf
1725.3 x 1362.5 x 100.0 mm
Bag Carrier Medium.stl
Bag Carrier Small.stl
Bag Carrier Large.stl
Bottle Cap Opener
bottle opener remix.stl
Base_Can_Opener.stl
logod.stl
Body_05*
DRAG right plate
DRAG left plate
DRAG centre plate
Blister Pack Opener.step
Body_08*2
central-loop-and-hook-button-and-zipper-hook.stl
Handle+scales.stl x 2
Connector+pin.stl x 2
Flipper Clipper mod for large size nailcutter.stl
Flipper the Clipper v2 (Thingiverse)
Spoon Holder.stl
Nut for Spoon Holder.stl
Shoe Horn.stl
Tube_Opener.stl
Arthritis Toothbrush Grip
One_Handed_Book_Holder.stl
Smartphone Magnification Stand.stl
Eye Drop Assist pliers (bottle 20 mm)
Eye Drop Assist pliers (bottle 22 mm)
Eye Drop Assist pliers (bottle 24 mm)
Eye Drop Assist pliers (bottle 25 mm)
Eye Drop Assist eyepiece 03 A
Eye Drop Assist eyepiece 03 B
Eye Drop Assist eyepiece 03 C
Eye Drop Assist eyepiece 04 D
Eye Drop Assist eyepiece 04 E

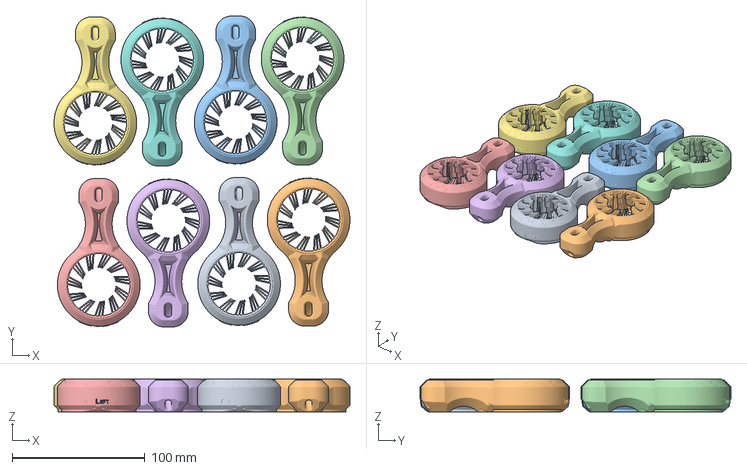
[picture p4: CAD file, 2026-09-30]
Full Plates/36 Younger Grip Lid Wrench (no magnets) - PLA x8.3mf
222.9 x 234.2 x 24.8 mm
YOUNGER__GRIP_NO Magnets_.stl x 8

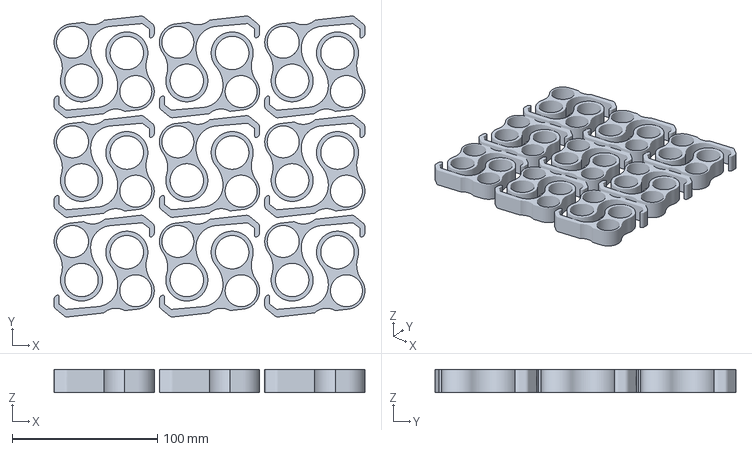
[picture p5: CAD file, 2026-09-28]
Full Plates/38 Pinky Saver 3 & Phone Stand - PLA x18.3mf
214.2 x 207.4 x 16.0 mm
pinky saver 3.stl x 18

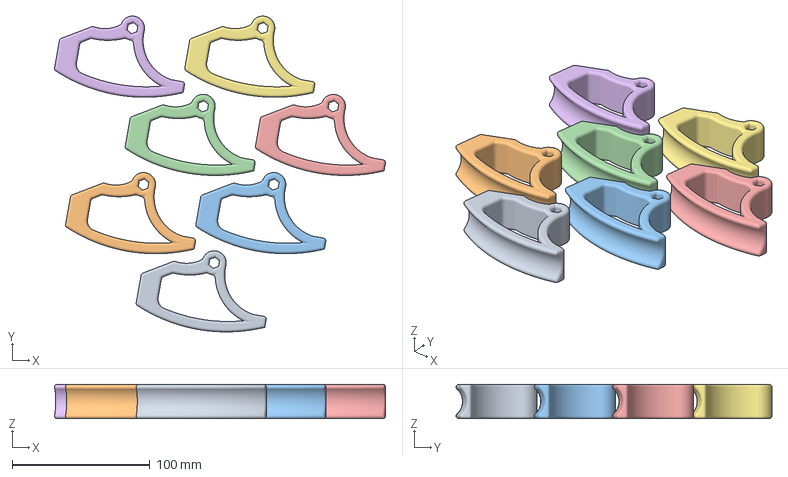
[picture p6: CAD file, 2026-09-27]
Full Plates/48 Adaptive Pencil Grip - PLA x7.3mf
240.1 x 229.1 x 25.0 mm
Adaptive Pencil Grip x 7

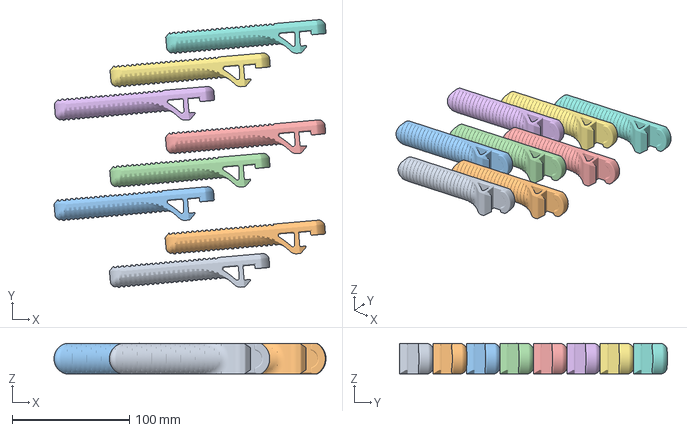
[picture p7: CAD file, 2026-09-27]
Full Plates/35 Jar Opener - Vacuum Releaser - PLA x8.3mf
232.0 x 228.5 x 26.2 mm

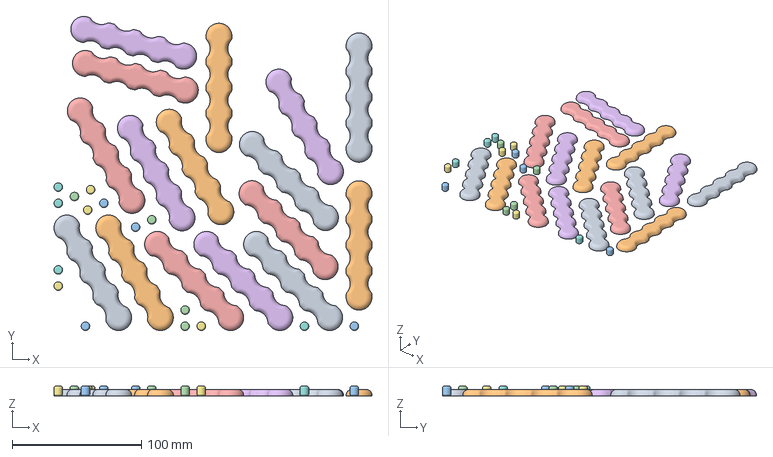
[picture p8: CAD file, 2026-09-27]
Full Plates/13 Clothes Button & Zipper Hook (handle kit, PLA) - PLA x8.3mf
245.8 x 242.7 x 7.60 mm
Handle+scales.stl x 16
Connector+pin.stl x 16

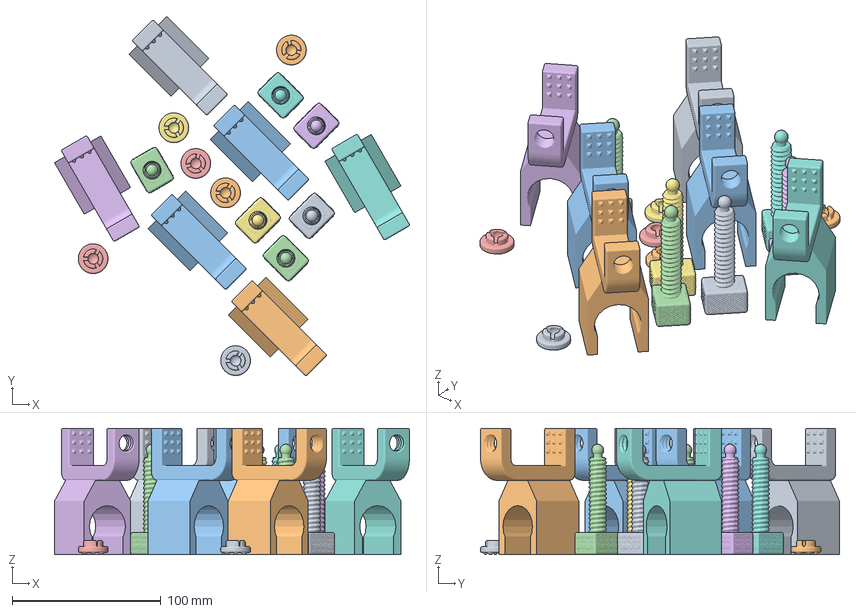
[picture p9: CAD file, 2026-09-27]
Full Plates/40 Adjustable Cane Holder (kit) - PLA x6.3mf
238.6 x 241.3 x 85.0 mm
Clamp protector x 6
Cane holder (textured clamp) x 6
Clamp screw (easy grip) x 6

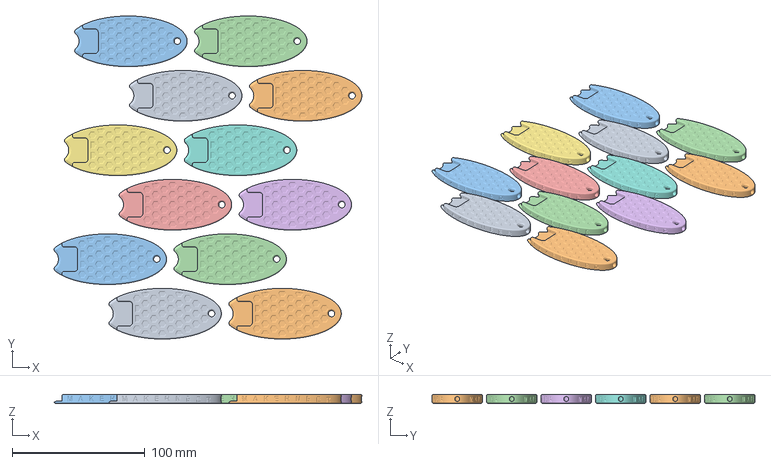
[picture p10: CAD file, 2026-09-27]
Full Plates/34 Soup Can Opener (no magnets) - PETG x12.3mf
231.7 x 243.1 x 6.75 mm
Soup Can Opener v5.stl x 12

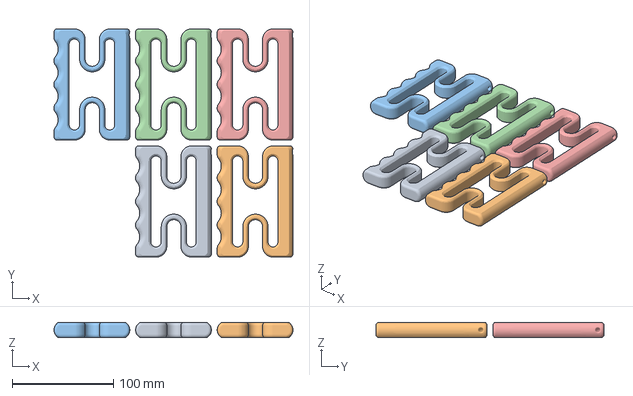
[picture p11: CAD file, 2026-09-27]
Full Plates/43 Hand Press - Grip Strengthener (Hard) - PETG x5.3mf
236.5 x 225.8 x 15.0 mm
Fingergrip Press Hard.stl x 5

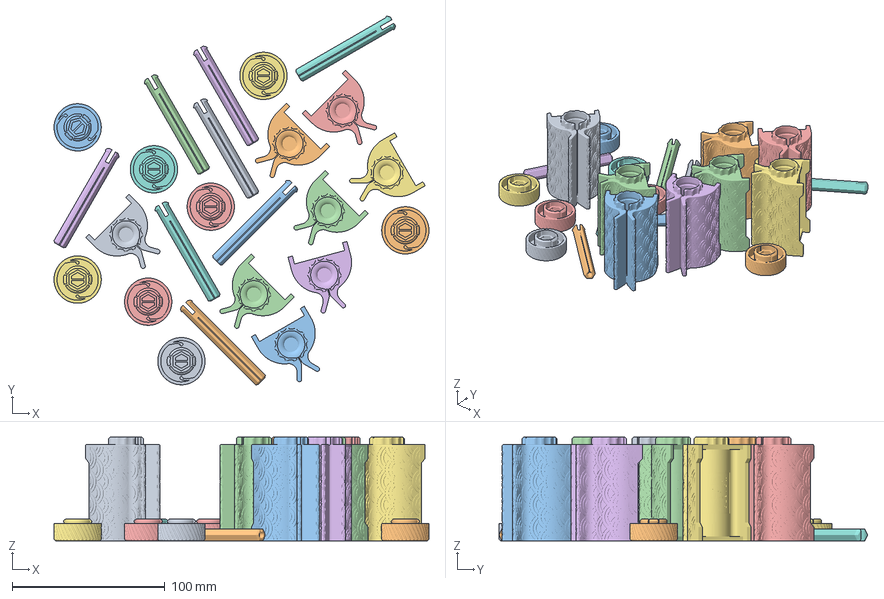
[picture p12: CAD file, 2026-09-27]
Full Plates/32 Toothpaste Squeezer, external gear (kit) - PLA x8.3mf
245.7 x 241.6 x 68.0 mm
Key head x 8
Key shaft 0.7 mm (standard) x 8
Squeezer base (Seigaiha pattern) x 8

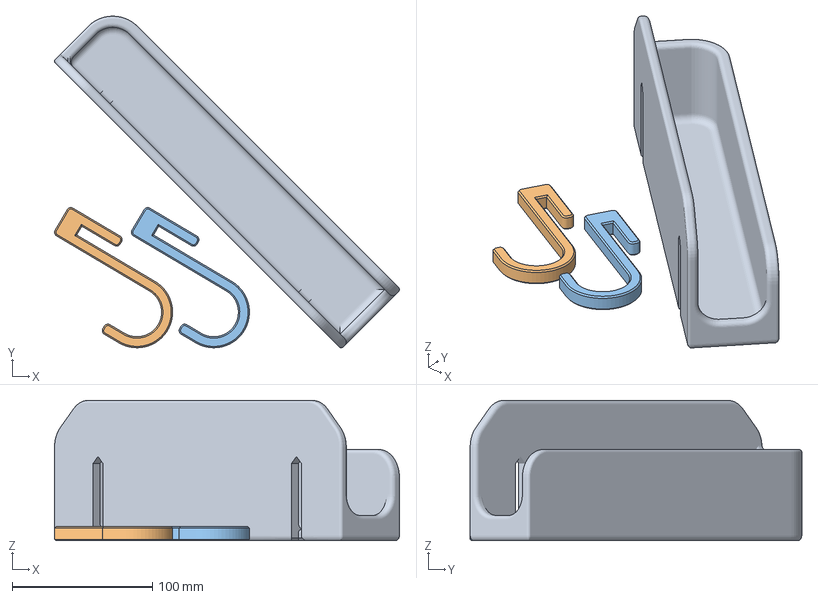
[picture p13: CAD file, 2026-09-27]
Full Plates/31 Bedside Hook-On Storage Box (kit) - PLA x1.3mf
245.8 x 236.3 x 100.0 mm
Bedside Holder v3.stl
Bedside Holder v3 hook.stl x 2

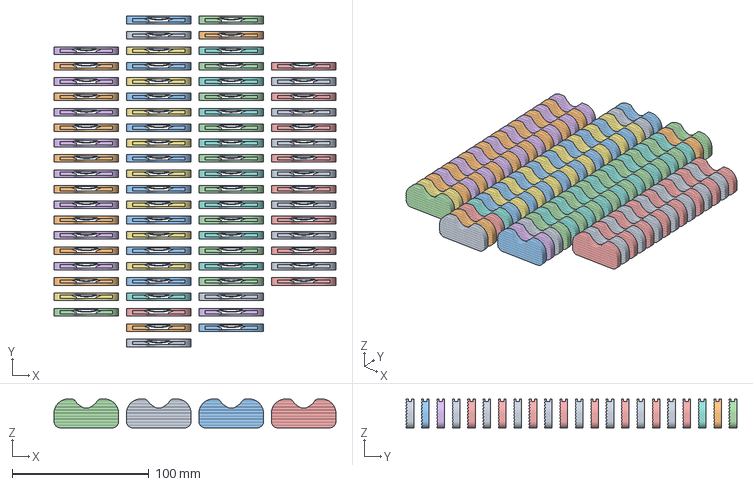
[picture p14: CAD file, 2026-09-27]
Full Plates/08 KeyWings - PETG x76.3mf
206.3 x 241.8 x 21.0 mm
Body_05* x 76

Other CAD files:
Full Plates/33 Chopstick Helper (small) - PLA x48.3mf
Full Plates/45 Pen Ball (kit) - PETG x4.3mf
Full Plates/47 Shoe Lifter - Boot Jack - PLA x2.3mf
Full Plates/44 Universal Travel Coffee Gimbal (kit) - PETG x2.3mf
Full Plates/01 Bag Carrier (Medium) - PLA x4.3mf
Full Plates/02 Bag Carrier (Small) - PLA x4.3mf
Full Plates/03 Bag Carrier (Large) - PLA x2.3mf
Full Plates/04 Bottle Cap Opener - PETG x8.3mf
Full Plates/05 Bottle Opener (three sizes, wide handle) - PETG x4.3mf
Full Plates/06 Assistive Can Tab Opener - PLA x30.3mf
Full Plates/07 OPENSESAME3000 Jar Tool - PETG x2.3mf
Full Plates/09 DRAG Assistive Writer (kit of 3) - PLA x2.3mf
Full Plates/11 Pill Popper - PETG x21.3mf
Full Plates/12 Clothes Button & Zipper Hook (hook, PETG) - PETG x9.3mf
Full Plates/14 Flipper Nail Clipper (large clippers) - PLA x3.3mf
Full Plates/15 Flipper the Clipper v2 (Thingiverse) - PLA x4.3mf
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

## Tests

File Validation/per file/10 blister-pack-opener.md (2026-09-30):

# 10 Blister Pack Opener

- file: `Full Plates/10 Blister Pack Opener - PETG x8.3mf`
- source: https://makerworld.com/en/models/1791626-blister-pack-opener#profileId-1909450
- reference 3mf: `New Devices/BlisterPackOpener_x8.3mf` (this plate, byte for byte)
- designer: MakeAble
- material: PETG (PETG P1S Tuned)
- on the plate: 8 copies (8 objects)

## Profile
| preset | layer | first layer | walls | infill | supports | brim | top/bottom |
|---|---|---|---|---|---|---|---|
| 0.20mm Standard @BBL X1C | 0.2 mm | 0.2 mm | 5 | 17% crosshatch | on tree(auto) | outer_only | 6/6 |

## How this file was made
Arranged by hand in Bambu Studio and delivered byte for byte: these tools did not pack, space, trim or re-bake it, so it keeps the project's own settings rather than per-object copies of them. The catalogue plate takes one copy from it.

## Validation
- Orca slice: passed - 8h 37m 51s, 237.2 g, 189.7 cm3
- per copie: 23.72 cm3
- the model page quotes 33 g per copy
- geometry check: clean (on the plate, clear of the excluded corner, no parts touching)
- spacing, kept as supplied: parts 5.75 mm apart (packed plates: 5 mm), 5.2 mm from the plate edge (5 mm), 16.6 mm from the excluded corner (8 mm)
- clamped for Orca only (the delivered file keeps Bambu's values): tree_support_wall_count, raft_first_layer_expansion

## Notes
- Tree supports and an outer brim are part of the designer's profile.
- Adjusted by hand in Bambu Studio from the earlier built plate (designer file `Pill Popper (PETG)/Pill+Opener.3mf`): all eight copies turned over onto their opposite face; mesh, settings and copy count unchanged.

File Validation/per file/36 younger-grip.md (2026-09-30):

# 36 Younger Grip Lid Wrench (no magnets)

- file: `Full Plates/36 Younger Grip Lid Wrench (no magnets) - PLA x8.3mf`
- source: https://makerworld.com/en/models/1493731-younger-grip-lid-wrench-arthritis-aid#profileId-1572614
- reference 3mf: `New Devices/PRJ___YOUNGER_GRIP_NO_Magnets_.3mf` (this plate, byte for byte)
- designer: SFYoung
- license: MakerWorld Standard Digital File License
- material: PLA (Bambu PLA Basic @BBL X1C)
- on the plate: 8 copies (8 objects)

## Profile
| preset | layer | first layer | walls | infill | supports | brim | top/bottom |
|---|---|---|---|---|---|---|---|
| 0.20mm Standard @BBL X1C | 0.2 mm | 0.2 mm | 3 | 10% gyroid | off | auto_brim | 5/3 |

## How this file was made
Arranged by hand in Bambu Studio and delivered byte for byte: these tools did not pack, space, trim or re-bake it, so it keeps the project's own settings rather than per-object copies of them. The catalogue plate takes one copy from it.

## Validation
- Orca slice: passed - 9h 20m 1s, 257.3 g, 204.2 cm3
- per copie: 25.52 cm3
- the model page quotes 33 g per copy
- geometry check: clean (on the plate, clear of the excluded corner, no parts touching)
- spacing, kept as supplied: parts 5 mm apart (packed plates: 5 mm), 0.7 mm from the plate edge (5 mm), 20.5 mm from the excluded corner (8 mm)
- clamped for Orca only (the delivered file keeps Bambu's values): tree_support_wall_count, raft_first_layer_expansion

## Advisories (nothing changed)
- YOUNGER__GRIP_NO Magnets_.stl: 240 mm2 of steep overhang with air under it (max drop 15.4 mm at z=15 mm) while supports are off in the designer's profile - worth a look at the preview

## Notes
- Replaces the earlier glue-in-magnets plate with the designer's 'NO MAGNETS' profile: the magnet cavities are filled in, so there is nothing to glue.
- The designer's single-colour plate, 8 copies; their profile (0.2 mm, 3 walls, 10% gyroid) on the P1S presets.
- Their height-range layer settings are kept: 0.12 mm layers over the finger-well overhang, 0.24 mm for the bridge above it, 0.2 mm elsewhere.

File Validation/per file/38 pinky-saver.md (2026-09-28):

# 38 Pinky Saver 3 & Phone Stand

- file: `Full Plates/38 Pinky Saver 3 & Phone Stand - PLA x18.3mf`
- source: https://makerworld.com/en/models/1842862-pinky-saver-3#profileId-1969044
- reference 3mf: `New Devices/PinkySaver3_x19.3mf` (this plate, byte for byte)
- designer: aqua3D
- license: MakerWorld Standard Digital File License
- material: PLA (Bambu PLA Basic @BBL X1C)
- on the plate: 18 copies (18 objects)

## Profile
| preset | layer | first layer | walls | infill | supports | brim | top/bottom |
|---|---|---|---|---|---|---|---|
| 0.20mm Standard @BBL X1C | 0.2 mm | 0.2 mm | 2 | 15% grid | off | auto_brim | 5/3 |

## How this file was made
Arranged by hand in Bambu Studio and delivered byte for byte: these tools did not pack, space, trim or re-bake it, so it keeps the project's own settings rather than per-object copies of them. The catalogue plate takes one copy from it.

## Validation
- Orca slice: passed - 5h 8m 33s, 159.0 g, 126.2 cm3
- per copie: 7.01 cm3
- the model page quotes 9 g per copy
- geometry check: clean (on the plate, clear of the excluded corner, no parts touching)
- spacing, kept as supplied: parts 3.25 mm apart (packed plates: 5 mm), 3 mm from the plate edge (5 mm), 3 mm from the excluded corner (8 mm)
- clamped for Orca only (the delivered file keeps Bambu's values): tree_support_wall_count, raft_first_layer_expansion

## Notes
- Replaces the earlier Pinky Saver & Phone Stand (standard holes, model 941286) with the designer's newer one-piece Pinky Saver 3.
- The designer's profile (0.2 mm, 2 walls, 15% infill) on the P1S presets.
- The supplied file is named x19 but holds 18 copies; Orca and Bambu's own plate thumbnail agree.

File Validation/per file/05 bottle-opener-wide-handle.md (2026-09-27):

# 05 Bottle Opener (three sizes, wide handle)

- file: `Full Plates/05 Bottle Opener (three sizes, wide handle) - PETG x4.3mf`
- source: https://makerworld.com/en/models/712423-bottle-opener-three-sizes-wider-handle#profileId-642822
- reference 3mf: `Bottle Opener (PETG)/Bottle+Opener+remix+without+support+material.3mf`
- designer: val
- material: PETG (PETG P1S Tuned)
- on the plate: 4 copies (4 objects)

## Profile
| preset | layer | first layer | walls | infill | supports | brim | top/bottom |
|---|---|---|---|---|---|---|---|
| 0.20mm Strength @BBL X1C | 0.2 mm | 0.2 mm | 5 | 15% honeycomb | on normal(auto) | auto_brim | 5/3 |

### Taken from the designer's file
| setting | P1S preset | designer |
|---|---|---|
| `independent_support_layer_height` | 1 | **0** |
| `overhang_totally_speed` | 10 | **50** |
| `sparse_infill_pattern` | grid | **cubic** |
| `support_type` | tree(auto) | **normal(auto)** |
| `tree_support_wall_count` | -1 | **0** |
| `wall_sequence` | inner wall/outer wall | **outer wall/inner wall** |

### Left at the P1S value (designer never changed it on their printer)
| setting | their file | P1S |
|---|---|---|
| `flush_multiplier` | 1 | **0.75** |
| `raft_first_layer_expansion` | 2 | **-1** |
| `top_area_threshold` | 100% | **200%** |

## Validation
- Orca slice: passed - 6h 46m 6s, 141.1 g, 112.9 cm3
- per copie: 28.22 cm3
- the designer's own file slices at 29.40 cm3 per copy (96% of that here)
- the model page quotes 35 g per copy
- geometry check: clean
- clamped for Orca only (the delivered file keeps Bambu's values): raft_first_layer_expansion

## Notes
- The designer's per-object settings (5 walls, 15% honeycomb, supports on, seam at the back) are carried over per object, as in the original.

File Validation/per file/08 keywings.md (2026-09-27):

# 08 KeyWings

- file: `Full Plates/08 KeyWings - PETG x76.3mf`
- source: https://makerworld.com/en/models/1688156-keywings-for-mobility-needs#profileId-1789186
- reference 3mf: `Key Holder (PETG)/KeyWings+v6+Bambu.3mf`
- designer: AlbertMakes
- material: PETG (PETG P1S Tuned)
- on the plate: 76 copies (76 objects)
- print-time cap: 88 copies fit on the plate; trimmed to 76 to stay under 14 h

## Profile
| preset | layer | first layer | walls | infill | supports | brim | top/bottom |
|---|---|---|---|---|---|---|---|
| 0.20mm Standard @BBL X1C | 0.2 mm | 0.2 mm | 3 | 20% grid | off | no_brim | 5/3 |

### Taken from the designer's file
| setting | P1S preset | designer |
|---|---|---|
| `bridge_speed` | 50 | **30** |
| `brim_type` | auto_brim | **no_brim** |
| `enable_arc_fitting` | 1 | **0** |
| `enable_prime_tower` | 1 | **0** |
| `inner_wall_line_width` | 0.45 | **0.5** |
| `max_travel_detour_distance` | 0 | **50** |
| `outer_wall_line_width` | 0.42 | **0.5** |
| `outer_wall_speed` | 200 | **100** |
| `overhang_2_4_speed` | 50 | **100** |
| `overhang_3_4_speed` | 30 | **100** |
| `overhang_4_4_speed` | 10 | **100** |
| `overhang_totally_speed` | 10 | **100** |
| `reduce_crossing_wall` | 0 | **1** |
| `skeleton_infill_density` | 15% | **20%** |
| `skin_infill_density` | 15% | **20%** |
| `sparse_infill_density` | 15% | **20%** |
| `tree_support_wall_count` | -1 | **0** |
| `wall_generator` | classic | **arachne** |
| `wall_loops` | 2 | **3** |
| `wall_sequence` | inner wall/outer wall | **outer wall/inner wall** |

### Left at the P1S value (designer never changed it on their printer)
| setting | their file | P1S |
|---|---|---|
| `default_acceleration` | 6000 | **10000** |
| `elefant_foot_compensation` | 0 | **0.15** |
| `flush_multiplier` | 1 | **0.75** |
| `raft_first_layer_expansion` | 2 | **-1** |
| `smooth_coefficient` | 80 | **150** |
| `travel_speed` | 700 | **500** |

## Validation
- Orca slice: passed - 13h 56m 36s, 237.0 g, 189.6 cm3
- per copie: 2.49 cm3
- the designer's own file slices at 2.63 cm3 per copy (95% of that here)
- the model page quotes 4 g per copy
- geometry check: clean
- clamped for Orca only (the delivered file keeps Bambu's values): raft_first_layer_expansion

## Advisories (nothing changed)
- Body_05*: tall and narrow (21 mm on a 6 mm footprint) with brim off in the designer's profile

## Notes
- Designer recommends PETG or nylon; brim is deliberately off in their profile.

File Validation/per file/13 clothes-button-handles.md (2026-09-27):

# 13 Clothes Button & Zipper Hook (handle kit, PLA)

- file: `Full Plates/13 Clothes Button & Zipper Hook (handle kit, PLA) - PLA x8.3mf`
- source: https://makerworld.com/en/models/423231-clothes-button-and-zipper-hook-helper
- reference 3mf: `Clothes Button and Zipper Aid (PETG + PLA)/central-loop-and-hook-button-and-zipper-hook.3mf`
- designer: Adapt3D_OT
- material: PLA (Bambu PLA Basic @BBL X1C)
- on the plate: 8 kits (32 objects)

## Profile
| preset | layer | first layer | walls | infill | supports | brim | top/bottom |
|---|---|---|---|---|---|---|---|
| 0.20mm Strength @BBL X1C | 0.2 mm | 0.2 mm | 3/6 | 25% gyroid | off | auto_brim | 5/3 |

### Taken from the designer's file
| setting | P1S preset | designer |
|---|---|---|
| `overhang_totally_speed` | 10 | **50** |
| `sparse_infill_pattern` | grid | **gyroid** |
| `support_type` | tree(auto) | **normal(auto)** |
| `tree_support_wall_count` | -1 | **0** |

### Left at the P1S value (designer never changed it on their printer)
| setting | their file | P1S |
|---|---|---|
| `flush_multiplier` | 1 | **0.75** |
| `raft_first_layer_expansion` | 2 | **-1** |
| `top_area_threshold` | 100% | **200%** |

## Validation
- Orca slice: passed - 4h 3m 50s, 98.6 g, 78.3 cm3
- per kit: 9.79 cm3
- the designer's own file slices at 9.81 cm3 per copy (100% of that here)
- geometry check: clean
- clamped for Orca only (the delivered file keeps Bambu's values): raft_first_layer_expansion

## Advisories (nothing changed)
- Handle+scales.stl: 1157 mm2 of steep overhang with air under it (max drop 5.0 mm at z=5 mm) while supports are off in the designer's profile - worth a look at the preview

## Notes
- One kit = 2 handle scales + 2 connector pins, which is what one hook needs.
- Pins are the designer's 95%-scaled version from the 3mf, not the loose STL.

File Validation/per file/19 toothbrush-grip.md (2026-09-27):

# 19 Arthritis Toothbrush Grip

- file: `Full Plates/19 Arthritis Toothbrush Grip - PLA x19.3mf`
- source: https://www.myminifactory.com/object/3d-print-arthritis-toothbrush-grip-77601
- reference 3mf: `Toothbrush Grip (PLA)/6066726cbda58_arthritis-toothbrush-grip/toofbrushgrip.stl`
- designer: MyMiniFactory
- material: PLA (Bambu PLA Basic @BBL X1C)
- on the plate: 19 copies (19 objects)
- print-time cap: 25 copies fit on the plate; trimmed to 19 to stay under 14 h

## Profile
| preset | layer | first layer | walls | infill | supports | brim | top/bottom |
|---|---|---|---|---|---|---|---|
| 0.20mm Standard @BBL X1C | 0.2 mm | 0.2 mm | 2 | 15% grid | off | auto_brim | 5/3 |

## Validation
- Orca slice: passed - 13h 23m 17s, 599.3 g, 475.6 cm3
- per copie: 25.03 cm3
- geometry check: clean
- clamped for Orca only (the delivered file keeps Bambu's values): tree_support_wall_count, raft_first_layer_expansion

## Notes
- No designer profile exists; P1S 0.20 mm Standard used.
- Heavy part: check the reported filament weight before starting a full plate.

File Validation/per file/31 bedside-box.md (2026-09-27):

# 31 Bedside Hook-On Storage Box (kit)

- file: `Full Plates/31 Bedside Hook-On Storage Box (kit) - PLA x1.3mf`
- source: https://makerworld.com/en/models/1051323-bedside-hook-on-storage-box-organizer#profileId-1038131
- reference 3mf: `New Devices/Bedside+Holder+v3.3mf`
- designer: StefB
- license: MakerWorld Standard Digital File License
- material: PLA (Bambu PLA Basic @BBL X1C)
- on the plate: 1 kit (3 objects)

## Profile
| preset | layer | first layer | walls | infill | supports | brim | top/bottom |
|---|---|---|---|---|---|---|---|
| 0.20mm Standard @BBL X1C | 0.2 mm | 0.2 mm | 2 | 15% grid | off | auto_brim | 5/3 |

### Taken from the designer's file
| setting | P1S preset | designer |
|---|---|---|
| `overhang_totally_speed` | 10 | **50** |
| `support_type` | tree(auto) | **normal(auto)** |
| `tree_support_wall_count` | -1 | **0** |

### Left at the P1S value (designer never changed it on their printer)
| setting | their file | P1S |
|---|---|---|
| `flush_multiplier` | 1 | **0.75** |
| `raft_first_layer_expansion` | 2 | **-1** |
| `top_area_threshold` | 100% | **200%** |

## Validation
- Orca slice: passed - 4h 12m 24s, 229.0 g, 181.7 cm3
- per kit: 181.72 cm3
- the designer's own file slices at 181.24 cm3 per copy (100% of that here)
- the model page quotes 223 g per copy
- geometry check: clean
- clamped for Orca only (the delivered file keeps Bambu's values): raft_first_layer_expansion

## Notes
- One kit = the storage box + two hooks, as on the designer's plate.
- The box is 240 mm long and lies diagonally across the bed. The packer cannot fit it inside the usual 5 mm margin, so the designer's own arrangement is used, centred (their X1 has the same bed and excluded corner as the P1S).
- The designer's variable layer height on the box is kept.

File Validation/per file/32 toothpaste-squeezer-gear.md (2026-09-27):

# 32 Toothpaste Squeezer, external gear (kit)

- file: `Full Plates/32 Toothpaste Squeezer, external gear (kit) - PLA x8.3mf`
- source: https://makerworld.com/en/models/2423006-toothpaste-squeezer-external-gear#profileId-2657457
- reference 3mf: `New Devices/ToothSqeez_ExterGear_SeigaihaPattern.3mf`
- designer: Tazio design
- license: MakerWorld Standard Digital File License
- material: PLA (Bambu PLA Basic @BBL X1C)
- on the plate: 8 kits (24 objects)
- print-time cap: 10 kits fit on the plate; trimmed to 8 to stay under 14 h

## Profile
| preset | layer | first layer | walls | infill | supports | brim | top/bottom |
|---|---|---|---|---|---|---|---|
| 0.20mm Standard @BBL X1C | 0.2 mm | 0.2 mm | 3 | 15%/25% grid/gyroid | off | auto_brim | 5/3 |

### Taken from the designer's file
| setting | P1S preset | designer |
|---|---|---|
| `bottom_shell_thickness` | 0 | **1** |
| `skeleton_infill_density` | 15% | **25%** |
| `skin_infill_density` | 15% | **25%** |
| `sparse_infill_density` | 15% | **25%** |
| `wall_loops` | 2 | **3** |

### Left at the P1S value (designer never changed it on their printer)
| setting | their file | P1S |
|---|---|---|
| `curr_bed_type` | Supertack Plate | **Textured PEI Plate** |
| `flush_multiplier` | 1 | **0.75** |

## Validation
- Orca slice: passed - 13h 55m 52s, 323.4 g, 256.6 cm3
- per kit: 32.08 cm3
- the designer's own file slices at 32.17 cm3 per copy (100% of that here)
- the model page quotes 42 g per copy
- geometry check: clean
- clamped for Orca only (the delivered file keeps Bambu's values): tree_support_wall_count, raft_first_layer_expansion

## Advisories (nothing changed)
- Squeezer base (Seigaiha pattern): 186 mm2 of steep overhang with air under it (max drop 57.0 mm at z=60 mm) while supports are off in the designer's profile - worth a look at the preview
- Key shaft 0.7 mm (standard): 100 mm2 of steep overhang with air under it (max drop 3.9 mm at z=6 mm) while supports are off in the designer's profile - worth a look at the preview

## Notes
- One kit = base + key head + the 0.7 mm 'Standard' key shaft. The designer also offers 1.0, 1.3 and 1.6 mm shafts for thicker tube ends (left out).
- The key parts keep the designer's own 15% gyroid; the base uses their 3 walls, 25% grid.
- Designer: PLA, PLA+, PETG or ASA - not silk PLA, which cracks at the key.

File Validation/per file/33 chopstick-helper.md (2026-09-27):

# 33 Chopstick Helper (small)

- file: `Full Plates/33 Chopstick Helper (small) - PLA x48.3mf`
- source: https://makerworld.com/en/models/1088273-chopstick-helper-refreshed-design#profileId-1082781
- reference 3mf: `New Devices/chopstick_helper_new_design_PLA_Small.3mf`
- designer: Daranto
- license: MakerWorld Standard Digital File License
- material: PLA (Bambu PLA Basic @BBL X1C)
- on the plate: 48 copies (48 objects)

## Profile
| preset | layer | first layer | walls | infill | supports | brim | top/bottom |
|---|---|---|---|---|---|---|---|
| 0.20mm Standard @BBL X1C | 0.2 mm | 0.2 mm | 6 | 100% zig-zag | off | auto_brim | 1/1 |

### Taken from the designer's file
| setting | P1S preset | designer |
|---|---|---|
| `bottom_shell_layers` | 3 | **1** |
| `bottom_surface_pattern` | monotonic | **concentric** |
| `overhang_totally_speed` | 10 | **50** |
| `seam_position` | aligned | **back** |
| `sparse_infill_density` | 15% | **100%** |
| `sparse_infill_pattern` | grid | **zig-zag** |
| `support_type` | tree(auto) | **normal(auto)** |
| `top_shell_layers` | 5 | **1** |
| `top_surface_pattern` | monotonicline | **concentric** |
| `tree_support_wall_count` | -1 | **0** |
| `wall_loops` | 2 | **6** |

### Left at the P1S value (designer never changed it on their printer)
| setting | their file | P1S |
|---|---|---|
| `flush_multiplier` | 1 | **0.75** |
| `raft_first_layer_expansion` | 2 | **-1** |
| `top_area_threshold` | 100% | **200%** |

## Validation
- Orca slice: passed - 6h 18m 45s, 149.2 g, 118.4 cm3
- per copie: 2.47 cm3
- the designer's own file slices at 2.48 cm3 per copy (99% of that here)
- the model page quotes 4 g per copy
- geometry check: clean
- clamped for Orca only (the delivered file keeps Bambu's values): raft_first_layer_expansion

## Advisories (nothing changed)
- chopstick_helper_smooth.stl: 115 mm2 of steep overhang with air under it (max drop 6.1 mm at z=8 mm) while supports are off in the designer's profile - worth a look at the preview

## Notes
- Small size: 6.12 mm holes. Medium (6.80 mm) and large (7.75 mm) exist on the page.
- Designer's profile: 6 walls, 100% infill.

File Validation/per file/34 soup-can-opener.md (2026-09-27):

# 34 Soup Can Opener (no magnets)

- file: `Full Plates/34 Soup Can Opener (no magnets) - PETG x12.3mf`
- source: https://makerworld.com/en/models/1030162-soup-can-opener-for-poor-grip-strength#profileId-1012846
- reference 3mf: `New Devices/Soup+Can+Opener+-+no+pause+for+magnets.3mf`
- designer: Makerneer
- license: CC0
- material: PETG (PETG P1S Tuned)
- on the plate: 12 copies (12 objects)

## Profile
| preset | layer | first layer | walls | infill | supports | brim | top/bottom |
|---|---|---|---|---|---|---|---|
| 0.20mm Strength @BBL X1C | 0.2 mm | 0.2 mm | 4 | 30% adaptivecubic | off | auto_brim | 5/5 |

### Taken from the designer's file
| setting | P1S preset | designer |
|---|---|---|
| `bottom_shell_layers` | 3 | **5** |
| `fuzzy_skin_point_distance` | 0.8 | **0.6** |
| `infill_wall_overlap` | 15% | **33%** |
| `initial_layer_infill_speed` | 105 | **35** |
| `initial_layer_speed` | 50 | **35** |
| `line_width` | 0.42 | **0.48** |
| `outer_wall_line_width` | 0.42 | **0.48** |
| `overhang_totally_speed` | 10 | **50** |
| `sparse_infill_density` | 25% | **30%** |
| `sparse_infill_pattern` | grid | **adaptivecubic** |
| `support_type` | tree(auto) | **normal(auto)** |
| `top_surface_line_width` | 0.42 | **0.48** |
| `tree_support_wall_count` | -1 | **0** |
| `wall_generator` | classic | **arachne** |
| `wall_loops` | 6 | **4** |

### Left at the P1S value (designer never changed it on their printer)
| setting | their file | P1S |
|---|---|---|
| `flush_multiplier` | 1 | **0.75** |
| `raft_first_layer_expansion` | 2 | **-1** |
| `top_area_threshold` | 100% | **200%** |

## Validation
- Orca slice: passed - 6h 12m 36s, 143.7 g, 115.0 cm3
- per copie: 9.58 cm3
- the designer's own file slices at 9.82 cm3 per copy (98% of that here)
- the model page quotes 13 g per copy
- geometry check: clean
- clamped for Orca only (the delivered file keeps Bambu's values): raft_first_layer_expansion

## Advisories (nothing changed)
- Soup Can Opener v5.stl: 235 mm2 of steep overhang with air under it (max drop 3.7 mm at z=5 mm) while supports are off in the designer's profile - worth a look at the preview

## Notes
- The designer printed it in Bambu PETG HF, so PETG it is.
- The 'no magnets' profile: no pause, the magnet holes stay empty.

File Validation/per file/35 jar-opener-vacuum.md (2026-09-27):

# 35 Jar Opener / Vacuum Releaser

- file: `Full Plates/35 Jar Opener - Vacuum Releaser - PLA x8.3mf`
- source: https://makerworld.com/en/models/1642031-jar-opener-tuned-for-all-bambu-printers#profileId-1735123
- reference 3mf: `New Devices/Jar+Opener+Bambu+ULTRA+FAST.3mf`
- designer: AlbertMakes
- license: MakerWorld Standard Digital File License
- material: PLA (Bambu PLA Basic @BBL X1C)
- on the plate: 8 copies (8 objects)

## Profile
| preset | layer | first layer | walls | infill | supports | brim | top/bottom |
|---|---|---|---|---|---|---|---|
| 0.24mm Draft @BBL X1C | 0.24 mm | 0.24 mm | 2 | 10% gyroid | off | no_brim | 3/3 |

### Taken from the designer's file
| setting | P1S preset | designer |
|---|---|---|
| `brim_type` | auto_brim | **no_brim** |
| `enable_circle_compensation` | 0 | **1** |
| `enable_overhang_speed` | 1 | **0** |
| `enable_prime_tower` | 1 | **0** |
| `initial_layer_print_height` | 0.2 | **0.24** |
| `precise_z_height` | 0 | **1** |
| `reduce_crossing_wall` | 0 | **1** |
| `skeleton_infill_density` | 15% | **10%** |
| `skin_infill_density` | 15% | **10%** |
| `sparse_infill_density` | 15% | **10%** |
| `sparse_infill_pattern` | grid | **gyroid** |
| `top_one_wall_type` | all top | **not apply** |
| `top_shell_layers` | 4 | **3** |
| `tree_support_wall_count` | -1 | **0** |
| `wall_sequence` | inner wall/outer wall | **outer wall/inner wall** |
| `z_direction_outwall_speed_continuous` | 0 | **1** |

### Left at the P1S value (designer never changed it on their printer)
| setting | their file | P1S |
|---|---|---|
| `curr_bed_type` | High Temp Plate | **Textured PEI Plate** |
| `default_acceleration` | 6000 | **10000** |
| `elefant_foot_compensation` | 0 | **0.15** |
| `flush_multiplier` | 1 | **0.75** |
| `raft_first_layer_expansion` | 2 | **-1** |
| `smooth_coefficient` | 80 | **150** |
| `travel_speed` | 700 | **500** |

### Deliberate changes
- mesh: four mesh vertices forming a 0.36 mm spike under the flat base were moved up onto the base; the part stood on the spike, its first layer was empty and the slicer refused it (the designer's own file fails the same way in OrcaSlicer)

## Validation
- Orca slice: passed - 6h 20m 5s, 161.4 g, 128.1 cm3
- per copie: 16.01 cm3
- the model page quotes 22 g per copy
- geometry check: clean
- clamped for Orca only (the delivered file keeps Bambu's values): raft_first_layer_expansion

## Advisories (nothing changed)
- Body_03: 359 mm2 of steep overhang with air under it (max drop 14.3 mm at z=20 mm) while supports are off in the designer's profile - worth a look at the preview

## Notes
- Mesh fix: four vertices formed a 0.1 x 0.5 mm spike 0.36 mm below the flat base, so the part stood on the spike and its first layer was empty - the slicer refuses it (the designer's own file fails the same way in OrcaSlicer). Those four vertices were moved up onto the base; nothing else in the mesh changed.
- Profile was an A1 mini 0.24 mm Draft profile; rebased onto the P1S 0.24 mm Draft.
- The page text suggests 0.2 mm, 6 walls, 60% infill; the downloaded profile uses 0.24 mm, 2 walls, 10% gyroid. The profile wins, as agreed.

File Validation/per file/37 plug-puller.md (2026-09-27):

# 37 Plug Puller (WATAP)

- file: `Full Plates/37 Plug Puller (WATAP) - PLA x9.3mf`
- source: https://makerworld.com/en/models/421822-plug-puller-assistive-technology-by-watap#profileId-324742
- reference 3mf: `New Devices/Plug+Puller+by+WATAP.3mf`
- designer: WATAP_3D
- license: CC BY-NC-SA
- material: PLA (Bambu PLA Basic @BBL X1C)
- on the plate: 9 copies (9 objects)
- also needed: 2 small zip ties (about 15 cm / 6 in) per puller

## Profile
| preset | layer | first layer | walls | infill | supports | brim | top/bottom |
|---|---|---|---|---|---|---|---|
| 0.20mm Strength @BBL X1C | 0.2 mm | 0.2 mm | 3 | 25% gyroid | off | auto_brim | 5/3 |

### Taken from the designer's file
| setting | P1S preset | designer |
|---|---|---|
| `overhang_totally_speed` | 10 | **50** |
| `sparse_infill_pattern` | grid | **gyroid** |
| `support_type` | tree(auto) | **normal(manual)** |
| `tree_support_wall_count` | -1 | **0** |
| `wall_loops` | 6 | **3** |

### Left at the P1S value (designer never changed it on their printer)
| setting | their file | P1S |
|---|---|---|
| `flush_multiplier` | 1 | **0.75** |
| `raft_first_layer_expansion` | 2 | **-1** |
| `top_area_threshold` | 100% | **200%** |

## Validation
- Orca slice: passed - 2h 59m 51s, 84.2 g, 66.8 cm3
- per copie: 7.42 cm3
- the designer's own file slices at 7.59 cm3 per copy (98% of that here)
- the model page quotes 10 g per copy
- geometry check: clean
- clamped for Orca only (the delivered file keeps Bambu's values): raft_first_layer_expansion

## Advisories (nothing changed)
- Plug Puller WATAP.stl: 156 mm2 of steep overhang with air under it (max drop 0.8 mm at z=1 mm) while supports are off in the designer's profile - worth a look at the preview

## Notes
- The designer's variable layer height is kept.

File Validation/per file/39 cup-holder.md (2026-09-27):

# 39 Universal Cup Holder (kit)

- file: `Full Plates/39 Universal Cup Holder (kit) - PLA x1.3mf`
- source: https://makerworld.com/en/models/1969980-universal-cup-holder#profileId-2118034
- reference 3mf: `New Devices/STOLLER_CUP_HOLDER_v2.0.3mf`
- designer: RED_eleven
- license: MakerWorld Standard Digital File License
- material: PLA (Bambu PLA Basic @BBL X1C)
- on the plate: 1 kit (10 objects)

## Profile
| preset | layer | first layer | walls | infill | supports | brim | top/bottom |
|---|---|---|---|---|---|---|---|
| 0.20mm Standard @BBL X1C | 0.2 mm | 0.2 mm | 6 | 15% grid | on tree(auto) | brim_ears | 5/3 |

### Taken from the designer's file
| setting | P1S preset | designer |
|---|---|---|
| `brim_type` | auto_brim | **brim_ears** |
| `enable_support` | 0 | **1** |
| `wall_loops` | 2 | **6** |

### Left at the P1S value (designer never changed it on their printer)
| setting | their file | P1S |
|---|---|---|
| `flush_multiplier` | 0.5 | **0.75** |

## Validation
- Orca slice: passed - 5h 7m 16s, 201.8 g, 160.2 cm3
- per kit: 160.19 cm3
- the designer's own file slices at 162.70 cm3 per copy (98% of that here)
- the model page quotes 200 g per copy
- geometry check: clean
- clamped for Orca only (the delivered file keeps Bambu's values): tree_support_wall_count, raft_first_layer_expansion

## Notes
- One kit = cup, both clamp halves, knob, spacer, the two halves of the split screw and three gripping fingers - the designer's 'Cup Holder & Clamp V2' plate.
- Designer's profile: 6 walls, tree supports, painted brim ears on the fingers (kept).

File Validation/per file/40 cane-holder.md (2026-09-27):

# 40 Adjustable Cane Holder (kit)

- file: `Full Plates/40 Adjustable Cane Holder (kit) - PLA x6.3mf`
- source: https://www.printables.com/model/203631-adjustable-cane-holder
- source files: `New Devices/adjustable-cane-holder-model_files/Recommended Print Files/texture_on_cane_holder_v3.stl`, `New Devices/adjustable-cane-holder-model_files/Recommended Print Files/alt_screw_updates.stl`, `New Devices/adjustable-cane-holder-model_files/Recommended Print Files/clamp_protector_tri.stl`
- designer: newhouse24 (Printables)
- license: CC BY-NC-SA 4.0
- material: PLA (Bambu PLA Basic @BBL X1C)
- on the plate: 6 kits (18 objects)
- print-time cap: 10 kits fit on the plate; trimmed to 6 to stay under 14 h

## Profile
| preset | layer | first layer | walls | infill | supports | brim | top/bottom |
|---|---|---|---|---|---|---|---|
| 0.20mm Standard @BBL X1C | 0.2 mm | 0.2 mm | 2 | 60% grid | on tree(auto) | auto_brim/outer_only | 5/3 |

### Deliberate changes
- `enable_support`: 0 -> **1**
- `skeleton_infill_density`: 15% -> **60%**
- `skin_infill_density`: 15% -> **60%**
- `sparse_infill_density`: 15% -> **60%**
- `support_base_pattern_spacing`: 2.5 -> **4**
- `support_on_build_plate_only`: 0 -> **1**

### Per-part settings
- Clamp screw (easy grip): `brim_type` = **outer_only**, `brim_width` = **5**

## Validation
- Orca slice: passed - 12h 45m 2s, 413.3 g, 328.0 cm3
- per kit: 54.66 cm3
- geometry check: clean
- clamped for Orca only (the delivered file keeps Bambu's values): tree_support_wall_count, raft_first_layer_expansion

## Notes
- The page's 'Recommended Print Files': textured holder, easy-grip screw, textured clamp protector.
- Designer's stated settings: 60% infill, supports touching the build plate at about 10% density (support line spacing 4 mm), a brim for the screw. Everything else is the P1S 0.20 mm Standard.

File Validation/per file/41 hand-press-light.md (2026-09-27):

# 41 Hand Press / Grip Strengthener (Light)

- file: `Full Plates/41 Hand Press - Grip Strengthener (Light) - PETG x5.3mf`
- source: https://makerworld.com/en/models/531052-hand-press-grip-strengthening#profileId-447870
- reference 3mf: `New Devices/Fingergrip+Press (1).3mf`
- designer: Sakul
- license: MakerWorld Standard Digital File License
- material: PETG (PETG P1S Tuned)
- on the plate: 5 copies (5 objects)

## Profile
| preset | layer | first layer | walls | infill | supports | brim | top/bottom |
|---|---|---|---|---|---|---|---|
| 0.20mm Standard @BBL X1C | 0.2 mm | 0.2 mm | 4 | 15% triangles | off | auto_brim | 6/6 |

### Taken from the designer's file
| setting | P1S preset | designer |
|---|---|---|
| `bottom_shell_layers` | 3 | **6** |
| `brim_object_gap` | 0.1 | **0** |
| `brim_width` | 5 | **7** |
| `detect_thin_wall` | 0 | **1** |
| `ironing_flow` | 10% | **20%** |
| `overhang_totally_speed` | 10 | **50** |
| `sparse_infill_pattern` | grid | **triangles** |
| `support_on_build_plate_only` | 0 | **1** |
| `support_type` | tree(auto) | **normal(auto)** |
| `top_shell_layers` | 5 | **6** |
| `tree_support_wall_count` | -1 | **0** |
| `wall_loops` | 2 | **5** |

### Left at the P1S value (designer never changed it on their printer)
| setting | their file | P1S |
|---|---|---|
| `flush_multiplier` | 1 | **0.75** |
| `raft_first_layer_expansion` | 2 | **-1** |
| `top_area_threshold` | 100% | **200%** |

## Validation
- Orca slice: passed - 6h 43m 9s, 194.3 g, 155.4 cm3
- per copie: 31.09 cm3
- the designer's own file slices at 31.19 cm3 per copy (100% of that here)
- the model page quotes 39 g per copy
- geometry check: clean
- clamped for Orca only (the delivered file keeps Bambu's values): raft_first_layer_expansion

## Advisories (nothing changed)
- Fingergrip Press Light.stl: 67 mm2 of steep overhang with air under it (max drop 4.0 mm at z=10 mm) while supports are off in the designer's profile - worth a look at the preview

## Notes
- The light grip: 4 walls (the designer's per-object setting).
- Designer: print it in PETG, PLA tends to deform.

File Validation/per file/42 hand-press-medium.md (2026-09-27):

# 42 Hand Press / Grip Strengthener (Medium)

- file: `Full Plates/42 Hand Press - Grip Strengthener (Medium) - PETG x5.3mf`
- source: https://makerworld.com/en/models/531052-hand-press-grip-strengthening#profileId-447870
- reference 3mf: `New Devices/Fingergrip+Press (1).3mf`
- designer: Sakul
- license: MakerWorld Standard Digital File License
- material: PETG (PETG P1S Tuned)
- on the plate: 5 copies (5 objects)

## Profile
| preset | layer | first layer | walls | infill | supports | brim | top/bottom |
|---|---|---|---|---|---|---|---|
| 0.20mm Standard @BBL X1C | 0.2 mm | 0.2 mm | 5 | 15% triangles | off | auto_brim | 6/6 |

### Taken from the designer's file
| setting | P1S preset | designer |
|---|---|---|
| `bottom_shell_layers` | 3 | **6** |
| `brim_object_gap` | 0.1 | **0** |
| `brim_width` | 5 | **7** |
| `detect_thin_wall` | 0 | **1** |
| `ironing_flow` | 10% | **20%** |
| `overhang_totally_speed` | 10 | **50** |
| `sparse_infill_pattern` | grid | **triangles** |
| `support_on_build_plate_only` | 0 | **1** |
| `support_type` | tree(auto) | **normal(auto)** |
| `top_shell_layers` | 5 | **6** |
| `tree_support_wall_count` | -1 | **0** |
| `wall_loops` | 2 | **5** |

### Left at the P1S value (designer never changed it on their printer)
| setting | their file | P1S |
|---|---|---|
| `flush_multiplier` | 1 | **0.75** |
| `raft_first_layer_expansion` | 2 | **-1** |
| `top_area_threshold` | 100% | **200%** |

## Validation
- Orca slice: passed - 7h 33m 56s, 221.1 g, 176.9 cm3
- per copie: 35.38 cm3
- the designer's own file slices at 35.48 cm3 per copy (100% of that here)
- the model page quotes 45 g per copy
- geometry check: clean
- clamped for Orca only (the delivered file keeps Bambu's values): raft_first_layer_expansion

## Advisories (nothing changed)
- Fingergrip Press Medium.stl: 67 mm2 of steep overhang with air under it (max drop 4.0 mm at z=10 mm) while supports are off in the designer's profile - worth a look at the preview

## Notes
- The medium grip: 5 walls (the designer's per-object setting).
- Designer: print it in PETG, PLA tends to deform.

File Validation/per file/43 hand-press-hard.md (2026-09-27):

# 43 Hand Press / Grip Strengthener (Hard)

- file: `Full Plates/43 Hand Press - Grip Strengthener (Hard) - PETG x5.3mf`
- source: https://makerworld.com/en/models/531052-hand-press-grip-strengthening#profileId-447870
- reference 3mf: `New Devices/Fingergrip+Press (1).3mf`
- designer: Sakul
- license: MakerWorld Standard Digital File License
- material: PETG (PETG P1S Tuned)
- on the plate: 5 copies (5 objects)

## Profile
| preset | layer | first layer | walls | infill | supports | brim | top/bottom |
|---|---|---|---|---|---|---|---|
| 0.20mm Standard @BBL X1C | 0.2 mm | 0.2 mm | 6 | 15% triangles | off | auto_brim | 6/6 |

### Taken from the designer's file
| setting | P1S preset | designer |
|---|---|---|
| `bottom_shell_layers` | 3 | **6** |
| `brim_object_gap` | 0.1 | **0** |
| `brim_width` | 5 | **7** |
| `detect_thin_wall` | 0 | **1** |
| `ironing_flow` | 10% | **20%** |
| `overhang_totally_speed` | 10 | **50** |
| `sparse_infill_pattern` | grid | **triangles** |
| `support_on_build_plate_only` | 0 | **1** |
| `support_type` | tree(auto) | **normal(auto)** |
| `top_shell_layers` | 5 | **6** |
| `tree_support_wall_count` | -1 | **0** |
| `wall_loops` | 2 | **5** |

### Left at the P1S value (designer never changed it on their printer)
| setting | their file | P1S |
|---|---|---|
| `flush_multiplier` | 1 | **0.75** |
| `raft_first_layer_expansion` | 2 | **-1** |
| `top_area_threshold` | 100% | **200%** |

## Validation
- Orca slice: passed - 8h 13m 43s, 243.9 g, 195.2 cm3
- per copie: 39.03 cm3
- the designer's own file slices at 39.21 cm3 per copy (100% of that here)
- the model page quotes 49 g per copy
- geometry check: clean
- clamped for Orca only (the delivered file keeps Bambu's values): raft_first_layer_expansion

## Advisories (nothing changed)
- Fingergrip Press Hard.stl: 67 mm2 of steep overhang with air under it (max drop 4.0 mm at z=10 mm) while supports are off in the designer's profile - worth a look at the preview

## Notes
- The hard grip: 6 walls (the designer's per-object setting).
- Designer: print it in PETG, PLA tends to deform.

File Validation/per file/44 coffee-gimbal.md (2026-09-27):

# 44 Universal Travel Coffee Gimbal (kit)

- file: `Full Plates/44 Universal Travel Coffee Gimbal (kit) - PETG x2.3mf`
- source: https://www.printables.com/model/129329-universal-travel-coffee-gimbal
- source files: `New Devices/universal-travel-coffee-gimbal-model_files/Gimbal.stl`, `New Devices/universal-travel-coffee-gimbal-model_files/Clamp.stl`, `New Devices/universal-travel-coffee-gimbal-model_files/Bolt.stl`, `New Devices/universal-travel-coffee-gimbal-model_files/MPC Washer.stl`
- designer: mobiobi (Printables)
- license: CC BY-NC 4.0
- material: PETG (PETG P1S Tuned)
- on the plate: 2 kits (8 objects)

## Profile
| preset | layer | first layer | walls | infill | supports | brim | top/bottom |
|---|---|---|---|---|---|---|---|
| 0.20mm Standard @BBL X1C | 0.2 mm | 0.2 mm | 4 | 15% grid | some parts, tree(auto) | auto_brim | 5/3 |

### Deliberate changes
- `wall_loops`: 2 -> **4**

### Per-part settings
- Clamp: `enable_support` = **1**, `support_type` = **tree(auto)**, `support_on_build_plate_only` = **1**

## Validation
- Orca slice: passed - 10h 37m 33s, 287.1 g, 229.7 cm3
- per kit: 114.84 cm3
- geometry check: clean
- clamped for Orca only (the delivered file keeps Bambu's values): tree_support_wall_count, raft_first_layer_expansion

## Advisories (nothing changed)
- Gimbal: 327 mm2 of steep overhang with air under it (max drop 2.0 mm at z=14 mm) while supports are off in the designer's profile - worth a look at the preview
- Bolt: 86 mm2 of steep overhang with air under it (max drop 3.7 mm at z=4 mm) while supports are off in the designer's profile - worth a look at the preview

## Notes
- One kit = gimbal + clamp + bolt + washer. The optional long bolt, nut, cup and flat-surface adapters, vertical gimbal and TPU bar wrap are left out.
- Designer: 4 perimeters, no supports on the gimbal. The clamp has a large overhang in its print orientation, so it alone gets tree supports.
- PETG rather than PLA: it holds hot cups and may sit on a car dashboard.

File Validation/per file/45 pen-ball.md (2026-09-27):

# 45 Pen Ball (kit)

- file: `Full Plates/45 Pen Ball (kit) - PETG x4.3mf`
- source: https://www.thingiverse.com/thing:2810069
- source files: `New Devices/Pen Ball - 2810069/files/Pen_Ball_Top_v.1.0.0.STL`, `New Devices/Pen Ball - 2810069/files/Pen_Ball_Bottom_v.1.0.0.stl`
- designer: makersmakingchange (Thingiverse)
- license: CC BY-NC-SA
- material: PETG (PETG P1S Tuned)
- on the plate: 4 kits (8 objects)
- print-time cap: 6 kits fit on the plate; trimmed to 4 to stay under 14 h
- also needed: 5 x #6-32 x 3/4 in round-head screws + 5 x #6-32 hex nuts per ball

## Profile
| preset | layer | first layer | walls | infill | supports | brim | top/bottom |
|---|---|---|---|---|---|---|---|
| 0.20mm Standard @BBL X1C | 0.2 mm | 0.2 mm | 2 | 50% grid | on tree(auto) | auto_brim | 5/3 |

### Deliberate changes
- `enable_support`: 0 -> **1**
- `skeleton_infill_density`: 15% -> **50%**
- `skin_infill_density`: 15% -> **50%**
- `sparse_infill_density`: 15% -> **50%**
- `support_on_build_plate_only`: 0 -> **1**

## Validation
- Orca slice: passed - 11h 36m 55s, 261.4 g, 209.1 cm3
- per kit: 52.28 cm3
- geometry check: clean
- clamped for Orca only (the delivered file keeps Bambu's values): tree_support_wall_count, raft_first_layer_expansion

## Notes
- Designer's spec sheet: 0.2 mm layers, 50% infill, supports only in the centre cavity, both halves printed together. Build-plate-only supports reach just that cavity.
- Designer used ABS; PETG is the closest of the two filaments here.

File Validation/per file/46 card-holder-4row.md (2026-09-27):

# 46 Playing Card Holder (4 rows)

- file: `Full Plates/46 Playing Card Holder (4 rows) - PLA x4.3mf`
- source: https://www.thingiverse.com/thing:2863434
- reference 3mf: `New Devices/Full Size Playing Card Holder - 2863434/files/holder-4row.stl`
- designer: Djones1t (Thingiverse)
- license: CC BY
- material: PLA (Bambu PLA Basic @BBL X1C)
- on the plate: 4 copies (4 objects)

## Profile
| preset | layer | first layer | walls | infill | supports | brim | top/bottom |
|---|---|---|---|---|---|---|---|
| 0.20mm Standard @BBL X1C | 0.2 mm | 0.2 mm | 2 | 15% grid | off | auto_brim | 5/3 |

## Validation
- Orca slice: passed - 7h 25m 17s, 302.5 g, 240.1 cm3
- per copie: 60.02 cm3
- geometry check: clean
- clamped for Orca only (the delivered file keeps Bambu's values): tree_support_wall_count, raft_first_layer_expansion
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

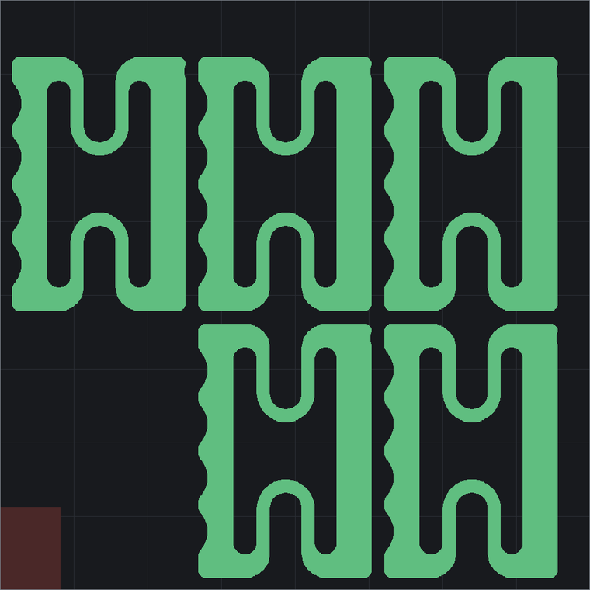
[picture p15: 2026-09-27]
Validation/plate previews/43 hand-press-hard.png

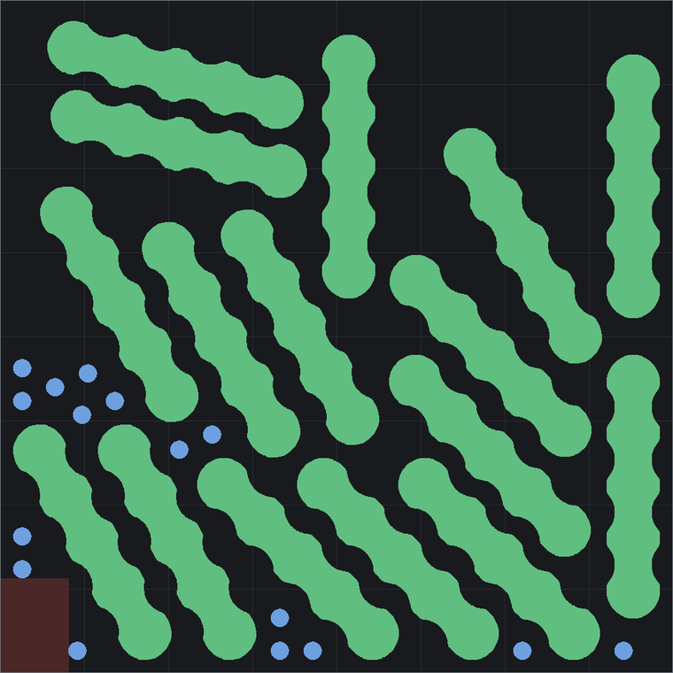
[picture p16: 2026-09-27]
Validation/plate previews/13 clothes-button-handles.png

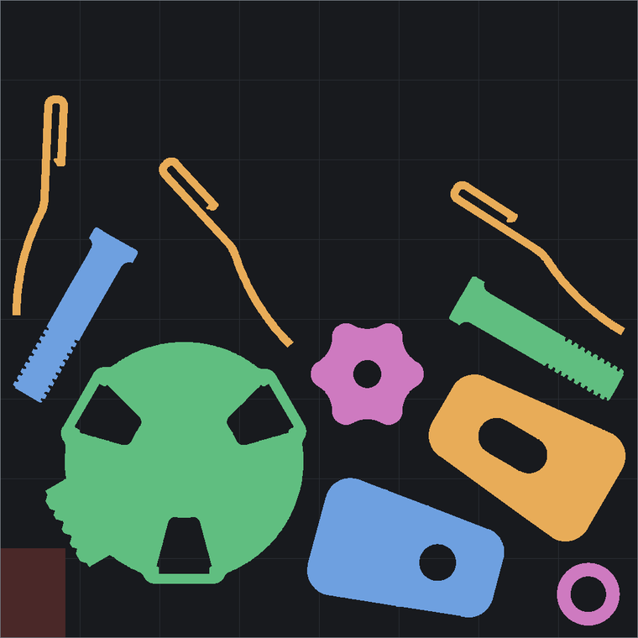
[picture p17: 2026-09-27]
Validation/plate previews/39 cup-holder.png

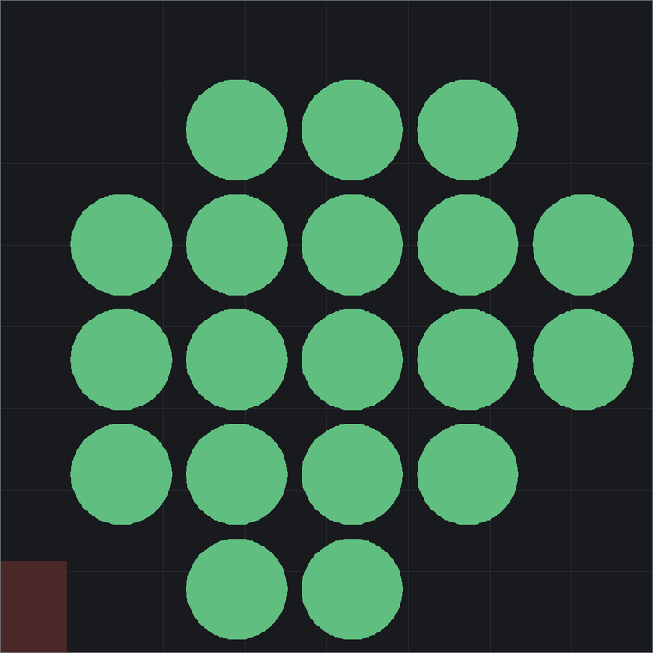
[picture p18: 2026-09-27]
Validation/plate previews/19 toothbrush-grip.png

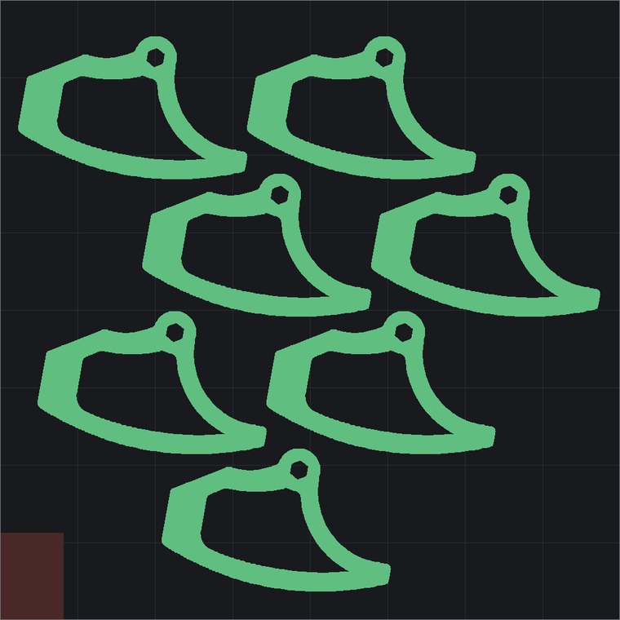
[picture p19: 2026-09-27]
Validation/plate previews/48 pencil-grip.png

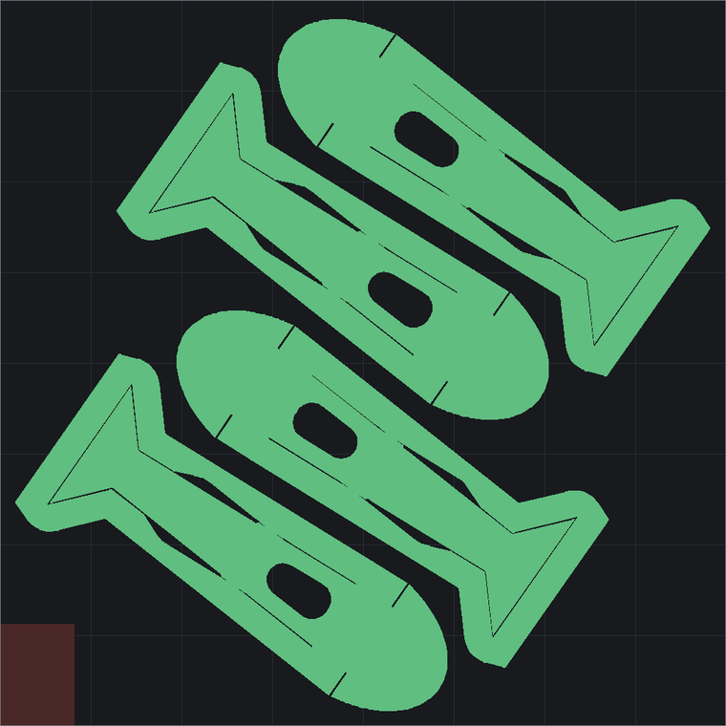
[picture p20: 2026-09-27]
Validation/plate previews/15 flipper-clipper-v2.png

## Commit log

2026-09-27 Add MakeAble assistive device print files for Bambu Lab P1S
    31 full-plate 3mf files, a one-device-per-plate catalogue, validation
    reports, plate previews and the build/check scripts. All set up for a
    P1S with 0.4 mm nozzle and textured PEI plate.
    [01 Bag Carrier (Medium) - PLA x4.3mf, 02 Bag Carrier (Small) - PLA x4.3mf, 03 Bag Carrier (Large) - PLA x2.3mf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]
2026-09-27 Remove toothpaste squeezer, add source links, renumber to 30 devices
    - Drop the Ratcheted Toothpaste Squeezer: its full plate, per-file page,
    plate preview, catalogue plate, data entries and README rows.
    - Renumber the Eye Drop Assist files 23-31 to 22-30 across Full Plates,
    per-file pages, previews, summary.csv and the validation data.
    - Rebuild the catalogue with catalogue.py: 30 plates, plates 1-21
    unchanged, eye-drop plates shifted up one slot; metadata now says
    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
    [22 Eye Drop Assist pliers (bottle 20 mm) - PLA x2.3mf, 22 Ratcheted Toothpaste Squeezer (kit) - PLA x15.3mf, 23 Eye Drop Assist pliers (bottle 22 mm) - PLA x2.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]
2026-09-27 Add 16 devices (files 31-48), a 14 h print-time cap and Catalogue 2
    - New full plates 31-48 for the second batch: Bedside Hook-On Storage Box,
    Toothpaste Squeezer (external gear), Chopstick Helper, Soup Can Opener,
    Jar Opener / Vacuum Releaser, Younger Grip (glue-in magnets), Plug Puller,
    Pinky Saver, Universal Cup Holder, Adjustable Cane Holder, Hand Press
    (Light / Medium / Hard), Universal Travel Coffee Gimbal, Pen Ball,
    Playing Card Holder (4 rows), Shoe Lifter / Boot Jack, Adaptive Pencil
    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
    [08 KeyWings - PETG x76.3mf, 08 KeyWings - PETG x88.3mf, 13 Clothes Button & Zipper Hook (handle kit, PLA) - PLA x8.3mf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]
2026-09-28 Replace 38 with Pinky Saver 3 (18 copies)
    Swap the Pinky Saver & Phone Stand (standard holes) x14 plate for the
    supplied Pinky Saver 3 plate by aqua3D, committed unchanged. It holds
    18 copies (the source file was named x19) and slices clean in Orca:
    5h 8m 33s, 159 g. Update the README rows, source link, summary.csv,
    the device's validation page and its plate preview.
    [38 Pinky Saver & Phone Stand (standard holes) - PLA x14.3mf, 38 Pinky Saver 3 & Phone Stand - PLA x18.3mf, summary.csv]
2026-09-28 Point devices.py at Pinky Saver 3 and rebuild Catalogue 2
    Device 38 is now a supplied plate: a new supplied=True entry option makes
    build.py copy the hand-arranged Bambu Studio file byte for byte instead of
    re-packing it, fitplate.py only slice and report it, and the self-check
    compare it against the file it came from. Its real clearances (3.25 mm
    between parts, 3 mm to the edge and the excluded corner) are recorded in
    place of the packer's 5 mm rules, and it is left out of the designer-file
    comparison, since it is its own reference.
    Catalogue 2 plate 8 now holds one Pinky Saver 3 (23m 42s, 8.9 g, 101% of
    the full plate's per-copy filament); every other plate is byte-identical.
    Self-check: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
    [Catalogue 2 - one device per plate.3mf, summary.csv]
2026-09-30 Replace 36 with Younger Grip (no magnets); keep hand-fixed plate 10
    36: swap the glue-in-magnets plate for the designer's NO MAGNETS profile
    (MakerWorld profile 1572614), supplied as an 8-copy plate arranged in
    Bambu Studio and committed byte for byte as a supplied plate. The magnet
    cavities are filled in, so the magnet hardware line is gone. Orca: 9h 20m
    1s, 257 g; the page quotes 33 g per copy for this plate.
    10: the Blister Pack Opener plate was fixed by hand in Bambu Studio (all
    eight copies turned over onto their opposite face, mesh and settings
    unchanged). It becomes a supplied plate so a rebuild cannot undo that.
    Orca: 8h 38m, 237 g (was 10h 28m, 251 g).
    Catalogue 1 plate 10 and Cat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
    [10 Blister Pack Opener - PETG x8.3mf, 36 Younger Grip Lid Wrench (glue-in magnets) - PLA x8.3mf, 36 Younger Grip Lid Wrench (no magnets) - PLA x8.3mf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]
